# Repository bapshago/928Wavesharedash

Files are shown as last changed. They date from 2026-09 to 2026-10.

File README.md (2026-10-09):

# 928 Waveshare Dash

Dash display for the Porsche 928 EV conversion, running on the
**Waveshare ESP32-P4-WIFI6-Touch-LCD-3.4C** (3.4" round 800×800 touch display).

This is a port of the [Angry Pixie web dash](https://github.com/bapshago/AngryPixieDash)
(`leaf_dash_v9`). The CAN decoding, gauges, warnings, odometer and settings are
the same, but instead of an ESP32 serving a web page to a tablet, the data is
drawn straight onto the round screen with LVGL.

The car has **two identical units**, one each side of the dash, running the same
firmware. A menuconfig setting picks which one a unit is:

| | Left screen | Right screen |
|---|---|---|
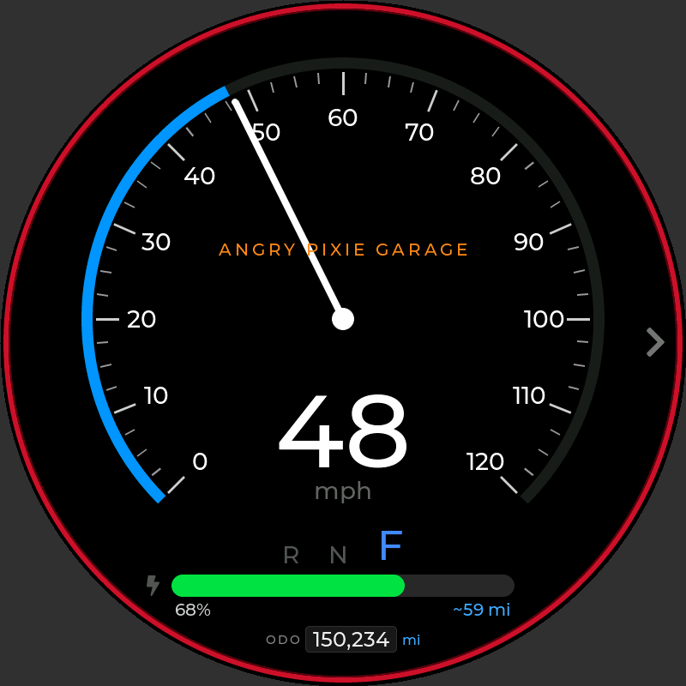
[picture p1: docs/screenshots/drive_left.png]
Left
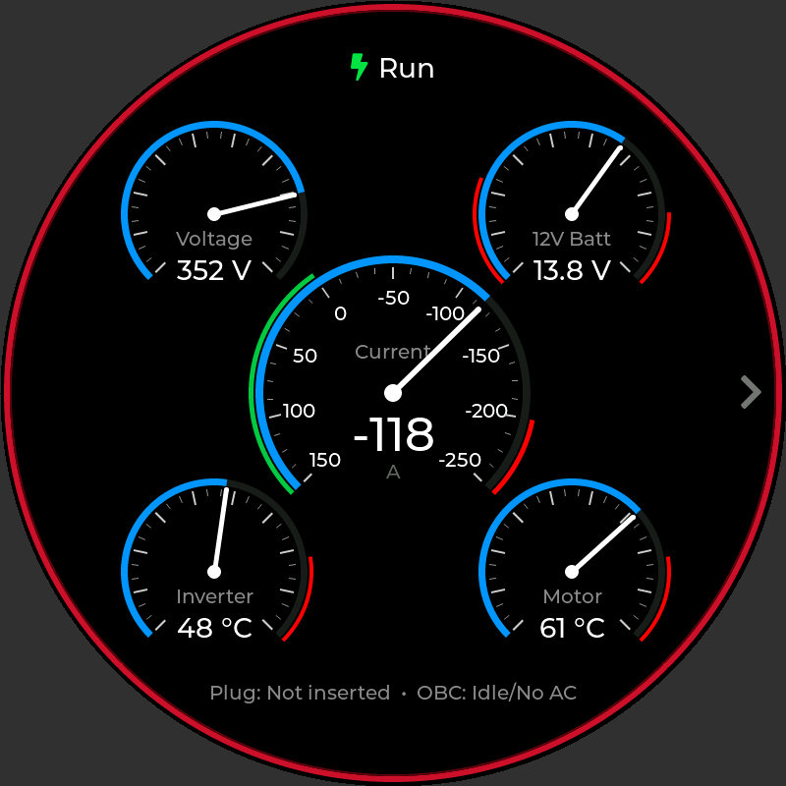
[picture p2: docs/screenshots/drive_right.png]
Right
| Driving |  |  |
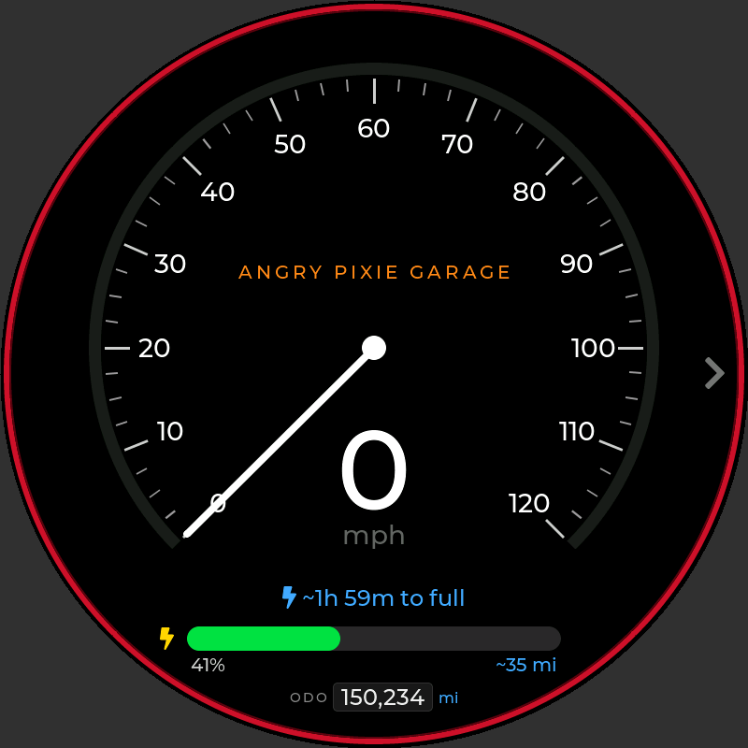
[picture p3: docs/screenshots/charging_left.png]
Charging
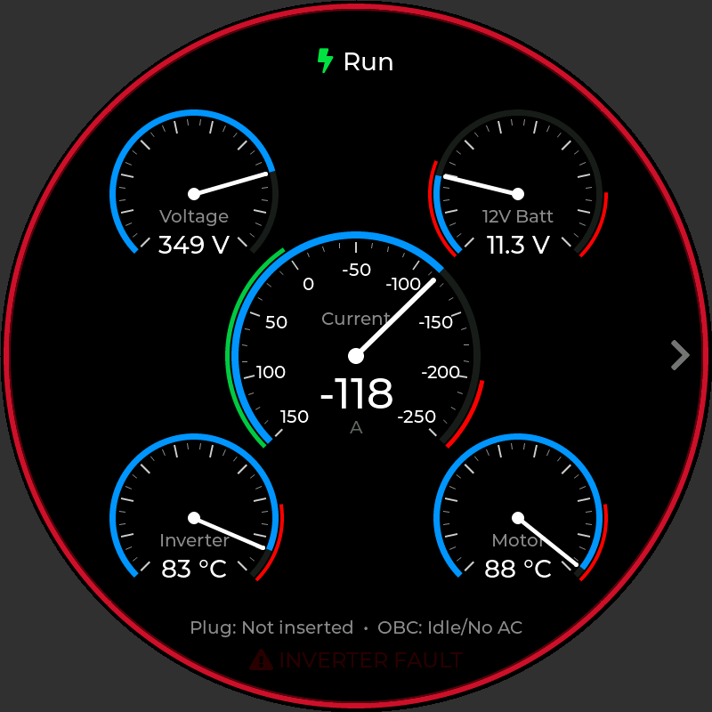
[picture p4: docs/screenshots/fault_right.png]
Fault
| Charging / fault |  |  |
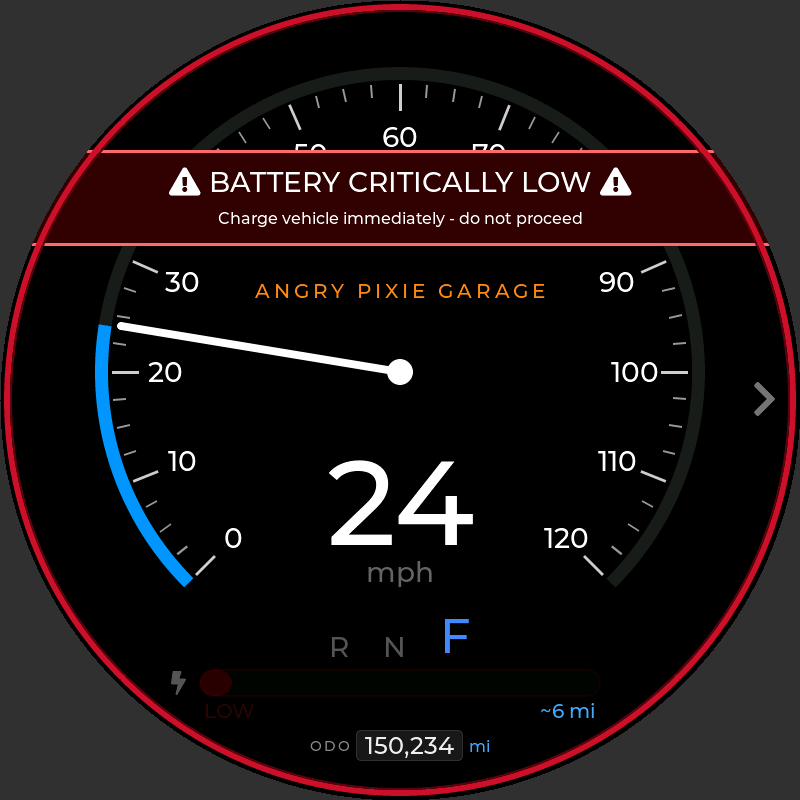
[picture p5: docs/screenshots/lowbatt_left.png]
Low battery
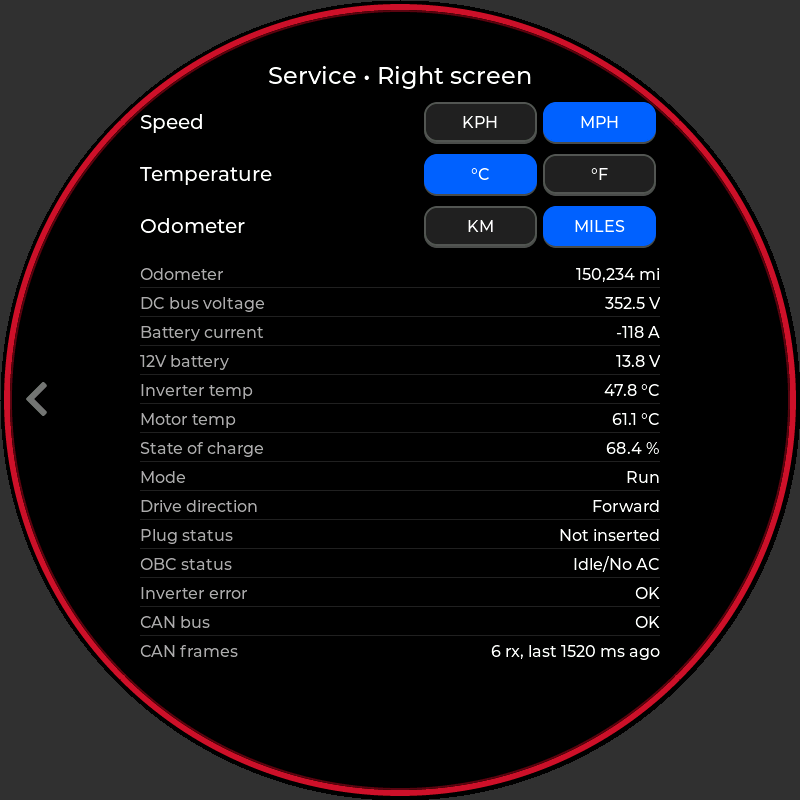
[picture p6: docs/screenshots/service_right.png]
Service
| Critically low battery / service page |  |  |

- **Left:** full-screen speed gauge, R / N / F (replaced by time-to-full while
  charging), state-of-charge bar with range, odometer, low-battery warning.
- **Right:** current gauge in the middle; pack voltage, 12V, inverter and motor
  temperature around it; op mode at the top; plug and charger status at the bottom.
- **Both:** the flashing inverter-fault warning and the service page.

*Screenshots are rendered by the desktop simulator (`sim/`) from the same UI code
the board runs; the grey corners are outside the round glass.*

## Features

Carried over from the web dash:

- Large speed gauge, kph (0–160) or mph (0–120)
- Small gauges: pack voltage, 12V aux battery (red below 11.5 V / above 15 V),
  inverter and motor temperature (°C 0–90 / °F 0–200, red in the top 20 %)
- Inverted current gauge: throttle swings clockwise to −250 A, regen to +150 A,
  green regen zone, 200–250 A redline
- R / N / F drive direction and op mode (Off, Run, Pre Charge, Pre Charge Failed, Charging)
- State-of-charge bar with range estimate (22 kWh pack, 3.9 mi/kWh); red below 15 %
- **Critical low-battery warning below 10 %**: flashing banner, bar and "LOW" readout
- Estimated time to full while charging
- Plug and on-board charger status; flashing inverter fault warning
- Odometer (miles or km), seeded to 150,000 miles on first boot and integrated from motor speed
- Service / Diagnostics screen (tap the arrow on the right edge, or swipe left) with speed, temperature and odometer unit
  toggles and all raw readings. Unit settings are stored per unit, so set them on both screens
- Unit settings and the odometer persist in flash (NVS); the odometer is written at
  most every 30 s to limit flash wear
- Red bezel ring to match the car's anodized gauge bezels

New on the round display:

- Needles ease between readings (the web page used a CSS transition)
- CAN bus state, frame counters and "last frame" age on the service screen
- 12V gauge shows one decimal (13.8 V rather than 14 V)

## Hardware

| Part | Notes |
|---|---|
| Waveshare ESP32-P4-WIFI6-Touch-LCD-3.4C | ESP32-P4, 32 MB PSRAM, 32 MB flash, 800×800 MIPI-DSI round IPS, capacitive touch |
| 3.3 V CAN transceiver: SN65HVD230 breakout | The ESP32-P4 has an on-chip CAN (TWAI) controller but no transceiver. The breakout plugs onto the board's 40-pin header |
| 12 V → 5 V buck converter (LM2596 module) | One per unit, with a USB-C lead soldered to its output to power the board. Set it to 5 V and check the polarity before plugging into the board |

Wiring (defaults; change them in `idf.py menuconfig` → *928 EV Dash*):

| 40-pin header | SN65HVD230 (breakout label) | |
|---|---|---|
| GPIO35 | D / TXD (CTX) | CAN TX |
| GPIO34 | R / RXD (CRX) | CAN RX |
| 3V3 | VCC (3V3) | |
| GND | GND | |
| | CANH / CANL | to the EV-CAN bus (ZombieVerter, Leaf inverter, PDM, BMS) |

GPIO35 is also the ESP32-P4's BOOT strapping pin. That's harmless here (the
transceiver input doesn't pull it low at power-up), but holding the board's BOOT
button will drive the CAN bus dominant, so don't press it with the car on.
The bus should already be terminated at both ends; remove the 120 Ω terminator on
the transceiver breakout unless the dash is at one end of the bus.

**Building a unit?** Follow the [build guide](docs/BUILD.md): parts, metalwork,
electronics prep, firmware, assembly, wiring into the car and commissioning.

The mechanical build is in [`hardware/mechanical/`](hardware/mechanical/README.md):
- cut files for the main instrument faceplate, the Waveshare mounting brackets,
  the buck converter bracket and the CAN bus wire bracket
- bend instructions, the hand-formed shroud, the assembly stack and hardware
- build photos

## CAN messages read (500 kbit/s)

| ID | Data |
|---|---|
| 0x1DA | DC bus voltage, motor speed, inverter error |
| 0x55A | Inverter and motor temperature |
| 0x390 | OBC / charge plug status |
| 0x55B | State of charge |
| 0x1DB | Battery current |
| 0x31A | ZombieVerter: drive direction, op mode, 12V aux voltage. Needs custom TX mappings, see [docs/ZombieVerter_CAN_Mappings.md](docs/ZombieVerter_CAN_Mappings.md) |
| 0x292 | 12V battery voltage (stock Leaf CAR-CAN, if present) |

## Building and flashing

Requires [ESP-IDF](https://docs.espressif.com/projects/esp-idf/en/latest/esp32p4/get-started/)
**v5.5 or newer** (builds verified on 5.5 and 6.1). The Waveshare BSP and LVGL are fetched automatically by the
component manager on the first build.

```sh
idf.py set-target esp32p4
idf.py build
idf.py -p /dev/ttyACM0 flash monitor     # COMx on Windows
```

Options under `idf.py menuconfig` → **928 EV Dash**:

| Option | Default | |
|---|---|---|
| Screen side | Left | **Left** or **Right**, see above. Set this differently on the two units |
| CAN TX / RX GPIO | 35 / 34 | Transceiver pins |
| CAN bitrate | 500000 | |
| Listen-only | off | On = the dash never ACKs or transmits. Leave off on a bench with only one transmitter |
| Test mode | off | No CAN needed: every gauge sweeps its full range up and back down over 20 s, SOC 100 → 0 %, and on/off states step through in turn. Test-mode distance is not added to the odometer |
| Backlight brightness | 100 % | |

The defaults target **ESP32-P4 silicon rev v1.x** (the chip on our board is
v1.3; the boot log and esptool print the revision). Newer boards ship with
v3.x silicon, and the two builds are not interchangeable: flashing reports
"requires chip revision in range ...". For a v3.x chip, build with
`idf.py -D SDKCONFIG_DEFAULTS="sdkconfig.defaults;sdkconfig.defaults.rev3_x" build`
after deleting `sdkconfig` and `build/`.

Drivetrain constants (gear ratio 7.94, tyre circumference 1.975 m, 22 kWh pack,
3.9 mi/kWh, initial odometer) are at the top of `main/core/dash_calc.h`.

## Previewing the screen without hardware

The simulator builds the same UI code for the PC and writes PNG screenshots.
It needs a C compiler and CMake:

```sh
cmake -S sim -B build-sim && cmake --build build-sim -j
./build-sim/dash_sim drive left out.png     # one scenario on one screen
./build-sim/dash_sim --all /tmp/shots        # every scenario, both screens
```

Scenarios: `drive`, `regen`, `charging`, `lowbatt`, `fault`, `nodata`,
`metric`, `service`, `test`. They're built from synthetic CAN frames run
through the real decoder, so they exercise the same path as the car.

## Tests

The CAN decoder and calculations are plain C and are tested on the PC:

```sh
cmake -S host_test -B build-test && cmake --build build-test && ./build-test/test_core
```

## Layout

```
main/
  main.c                boot: settings + CAN, then display + UI
  dash_model.c          ESP32 side: TWAI receive, NVS settings/odometer, test mode
  core/                 portable C, no ESP-IDF: state, Leaf/ZombieVerter decoder, calculations
  ui/                   LVGL: gauge widget, driver + service screens
sim/                    desktop renderer (LVGL on the PC → PNG)
host_test/              unit tests for main/core
docs/                   build guide, screenshots, ZombieVerter CAN mapping guide
hardware/mechanical/    cut files (DXF), bend diagrams, assembly notes, build photos
```

## Differences from the web dash

- **Battery current sign fix:** 0x1DB decoding now subtracts 2048 for negative
  values (the web dash subtracted 2047, so every negative reading was 1 A too high).
- **No false low-battery alarm at key-on:** SOC, pack voltage and current show
  "--" until their first CAN frame arrives. The web dash treated a missing SOC
  as 0 %, which flashed the critical-battery banner whenever data was missing.
- **Odometer display:** miles are computed as metres ÷ 1609.344 instead of
  km × 0.621371, which rounded 150,234 down to 150,233.
- **Current scale unchanged:** 0x1DB current is used at 1 A/bit, exactly as the
  web dash did. Some Leaf decodes list this signal as 0.5 A/bit, so compare the
  gauge with a clamp meter or your BMS and adjust `leaf_can.c` if it reads double.
- **Settings don't carry over:** the NVS namespace and keys match the web dash,
  but this is a different board, so the odometer seeds fresh at 150,000 miles.
  Change `DASH_ODO_INITIAL_MILES` before first boot to start from the car's real reading.

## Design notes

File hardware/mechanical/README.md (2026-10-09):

# Mechanical build

Parts, bending, the shroud and assembly for the dash pod. The DXF cut files are
in millimetres.

| File | Part | Qty (both units) | Material | How it's made |
|---|---|---|---|---|
| `SCS_MainInstrumentFaceplate_RV1_1.dxf` | Main instrument faceplate: two 90 mm gauge openings, mounting tab each end (416 × 120 mm flat) | 1 | 16 gauge (1/16") cold rolled steel | SendCutSend, then bent (below) |
| `SCS_WaveshareMountingBracket_RV1_1.dxf` | Waveshare mounting bracket: joins a Waveshare screen to the back of the faceplate (33 × 10 mm flat, two 4.5 mm holes) | 8 | 16 gauge (1/16") cold rolled steel | SendCutSend, then bent (below) |
| `SCS_BuckConverterBracket_V1_1.dxf` | Buck converter bracket, **6 round holes**: four 3 mm for the M2.5 standoffs, two 4.5 mm for M4 (attaches to the screen; flat, no bends) | 2 | 1/16" ABS | Laser cut |
| `SCS_CanBusWireBracket_V1_1.dxf` | CAN bus wire bracket, **2 round holes** (4.5 mm for M4) plus zip-tie slots; 24.8 × 88 mm (attaches to the screen; flat, no bends) | 2 | 1/16" ABS | Laser cut |
| *(no file: hand formed)* | Shroud: strip formed around the faceplate to meet the pod face | 1 | 18 gauge cold rolled steel, 3" × 31" strip | Hand formed, welded to the faceplate (below) |

## Ordering the steel parts from SendCutSend

Upload `SCS_MainInstrumentFaceplate_RV1_1.dxf` and
`SCS_WaveshareMountingBracket_RV1_1.dxf` (quantity 8), confirm the units are
**millimetres** when the part preview loads (the faceplate should show about
416 × 120 mm), and choose **cold rolled steel, 16 gauge**. SendCutSend's 16 ga steel is nominally
0.060" (1.52 mm), close enough to 1/16" (0.0625") for these parts.

## Bending the main instrument faceplate

Bend lines on the main instrument faceplate

Each end of the faceplate has a tab with a 6.5 mm hole near its top. Bend each tab
**90°** on a line **20 mm down from the top edge of the tab** (the end with the
hole). The tab is free of the main plate for its top 25 mm, so the bend line sits
5 mm above where the tab joins the faceplate; the 20 mm flap with the hole is what
folds over.

## Bending the Waveshare mounting brackets

Bend lines on the Waveshare mounting bracket

Two 90° bends in opposite directions make a **5 mm jog** (a Z shape):

1. **Bend 1:** 2 mm in from the edge of one hole, toward the middle of the part
   (about 9.3 mm from that end).
2. **Bend 2:** 5 mm past bend 1 (about 14.3 mm from the same end), back the other
   way, so the two hole ends finish parallel and 5 mm apart.

The holes sit almost exactly symmetric on the strip, so either end can be the start.

## Shroud

The shroud closes the gap between the faceplate and the face of the 928 instrument pod.
It isn't a cut file: it's hand formed from a **3" × 31" strip of 18 gauge cold
rolled steel**, using the pod as the guide.

1. **Position:** the shroud runs just inside the four inner M4 bolt holes on the faceplate
   (185 mm and 230 mm from the left end), and about 10 mm inside the four outer
   holes (110 mm and 305 mm from the left end).
2. **Measure your pod:** bolt the faceplate into the pod and measure from the edge of the faceplate
   to the face of the pod at several points around it. On the first car the
   shroud was **10 mm** at its smallest and **33 mm** at its largest, with the
   trim cut at roughly **20°**. Other pods may differ, so measure yours rather
   than copying these numbers.
3. **Make a template first (recommended):** cut a 3" × 31" strip of posterboard,
   form it around the faceplate inside the pod and trim it until it meets the pod face all
   the way round. Then trace it onto the steel strip and cut. This gets an exact
   fit before any metal is cut.
4. **Form and close:** hand form the strip to shape against the pod and trim it to
   your measurements. Then weld the two ends of the strip together.
5. **Tack weld** the shroud to the faceplate, refit it in the pod and confirm the fit.
6. **Stitch weld** the shroud to the faceplate once the fit is right.
7. **Finish:** prep for paint, then epoxy primer and a **matte black** top coat.
   Matte black keeps reflections off the screens.

## Assembly stack

Each unit stacks from the front of the car backwards:

1. **Main instrument faceplate.** One faceplate carries both screens, one per
   gauge opening.
2. **Waveshare screen**, face forward through the opening.
3. **ABS brackets** (buck converter bracket and CAN bus wire bracket) against
   the back of the screen.
4. **Four Waveshare mounting brackets** over the ABS brackets. One end of each bracket
   screws into the screen through the ABS brackets. The 5 mm jog brings the other
   end forward onto the faceplate, where it bolts on.

## Power

The buck converter's 5 V output has a USB-C cable soldered on, which plugs into
the Waveshare screen. Before plugging it into the screen, set the output to
**5 V** and **check the polarity** at the USB-C end.

## Assembly hardware

| Joint | Hardware |
|---|---|
| Waveshare mounting bracket to the Waveshare screen, clamping the ABS brackets | M4 × 5 mm screws |
| Waveshare mounting bracket to the back of the faceplate | M4 bolts, flat washers, lock washers and nuts |
| Buck converter to its ABS bracket | M2.5 × 5 mm standoffs, screws and nuts |
| Wires to the brackets | Small zip ties through the notches in the brackets |

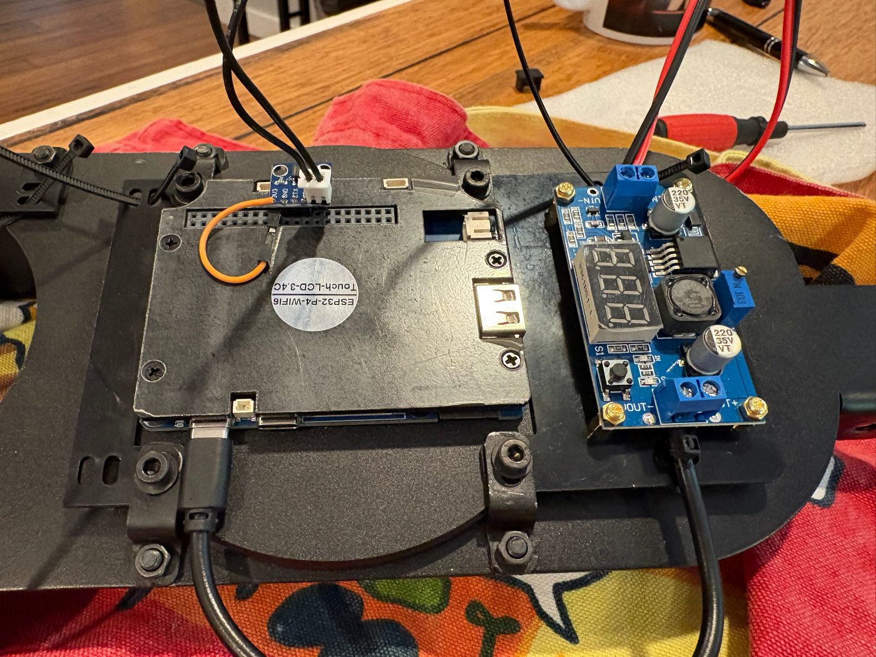
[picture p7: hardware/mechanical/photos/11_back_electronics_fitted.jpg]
Back of the main instrument faceplate with one unit assembled


*Back of the faceplate with one unit fitted:*
- *The Waveshare screen sits over a gauge opening, held by four Waveshare mounting brackets (two M4 fasteners each).*
- *The SN65HVD230 CAN transceiver plugs onto the screen's GPIO header.*
- *The LM2596 buck converter sits on M2.5 standoffs to the right.*
- *Zip ties through the bracket notches hold the wiring.*

Step-by-step assembly, wiring and commissioning are in the
[build guide](../../docs/BUILD.md).

## Build photos

In build order. All photos are in `photos/`.

**Test fit of the flat faceplate in the original 928 instrument pod**, with
one screen on its four Waveshare mounting brackets. The second opening shows the
bracket holes before its brackets go on.

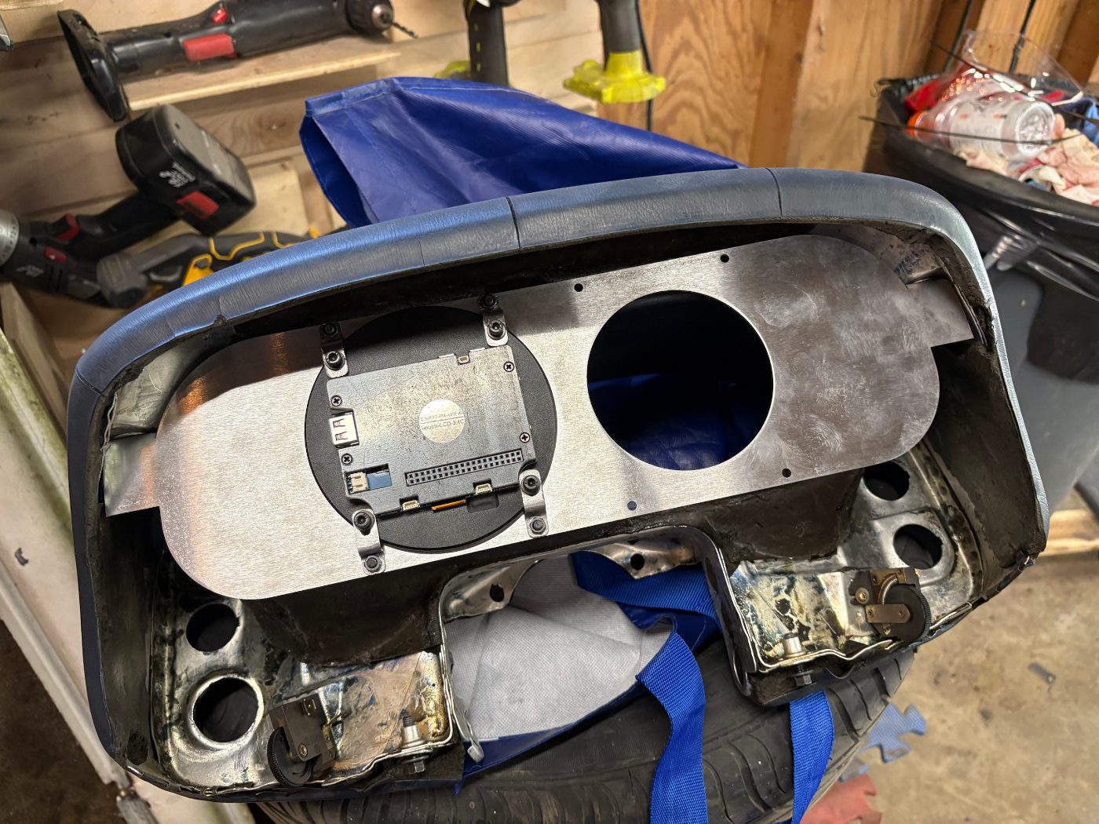
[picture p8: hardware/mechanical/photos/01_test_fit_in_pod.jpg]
Test fit in the pod

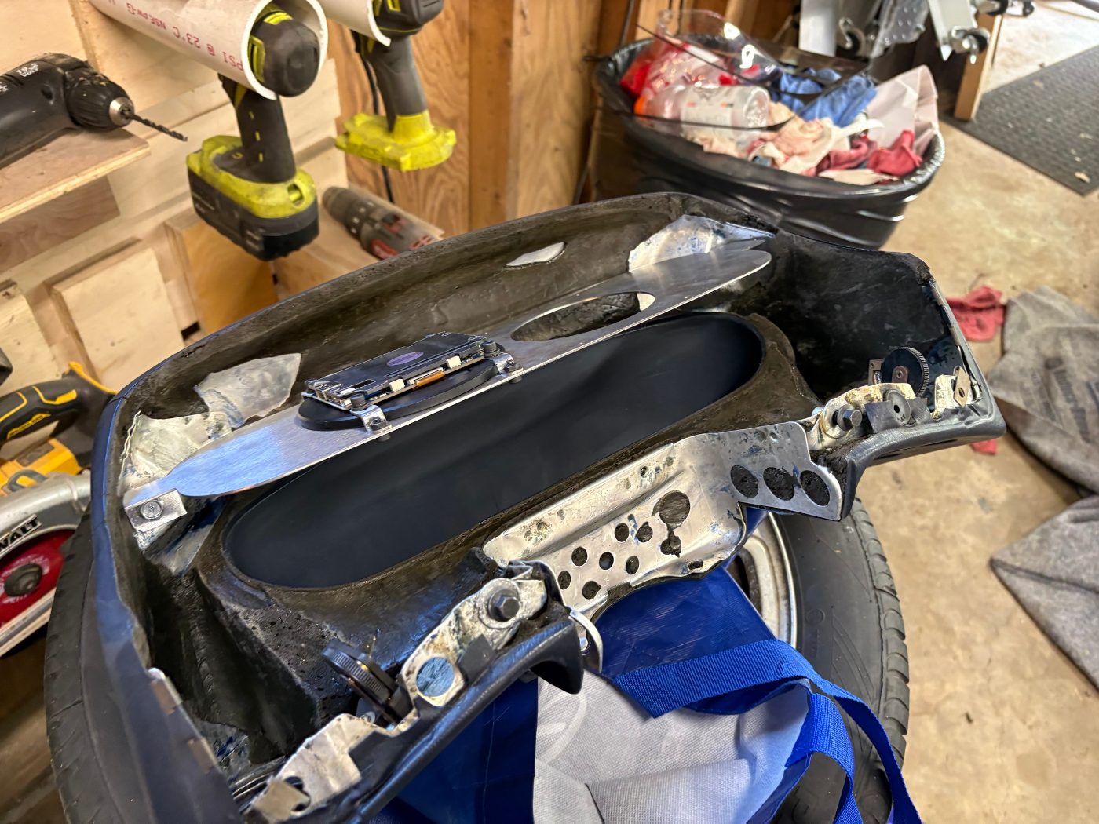
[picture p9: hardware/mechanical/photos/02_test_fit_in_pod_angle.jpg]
Test fit in the pod, side angle


**Back of the faceplate** with the Waveshare mounting brackets bolted on (M4 bolts, washers, lock
washers and nuts) and the end tabs bent.

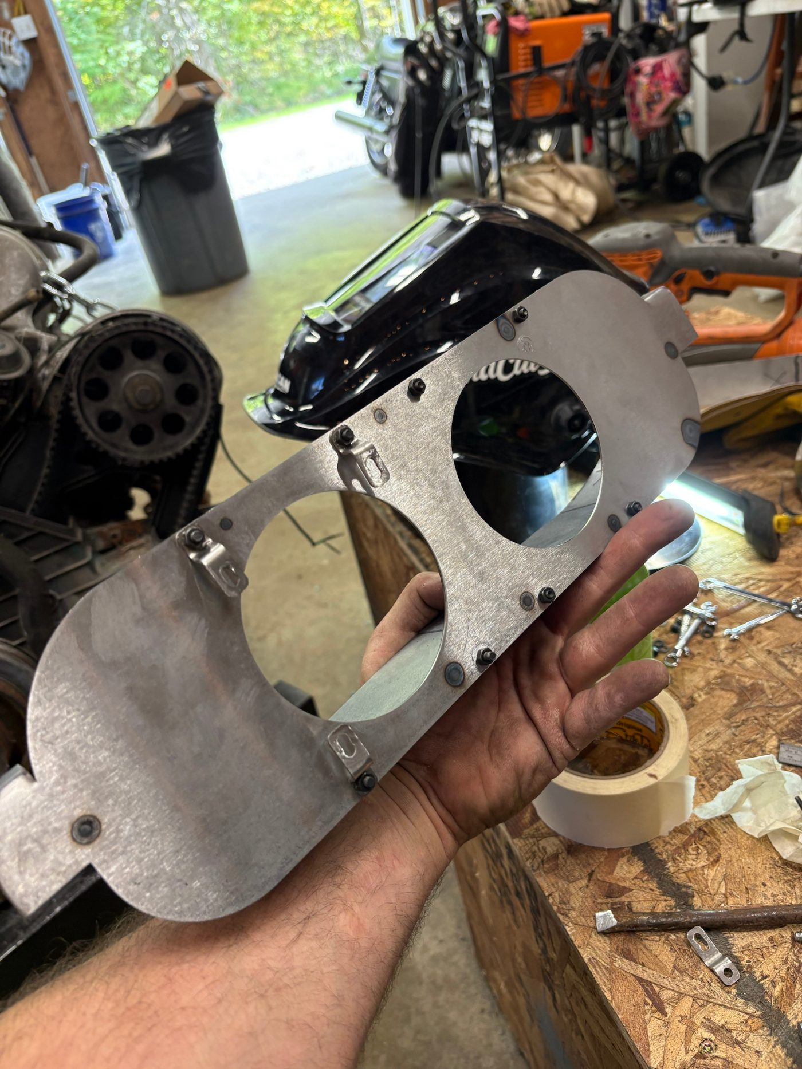
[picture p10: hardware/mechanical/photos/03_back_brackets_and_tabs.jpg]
Back of the faceplate with brackets


**Steel shroud** (see [Shroud](#shroud)), hand formed, ends welded, then tacked and
stitch welded to the faceplate.

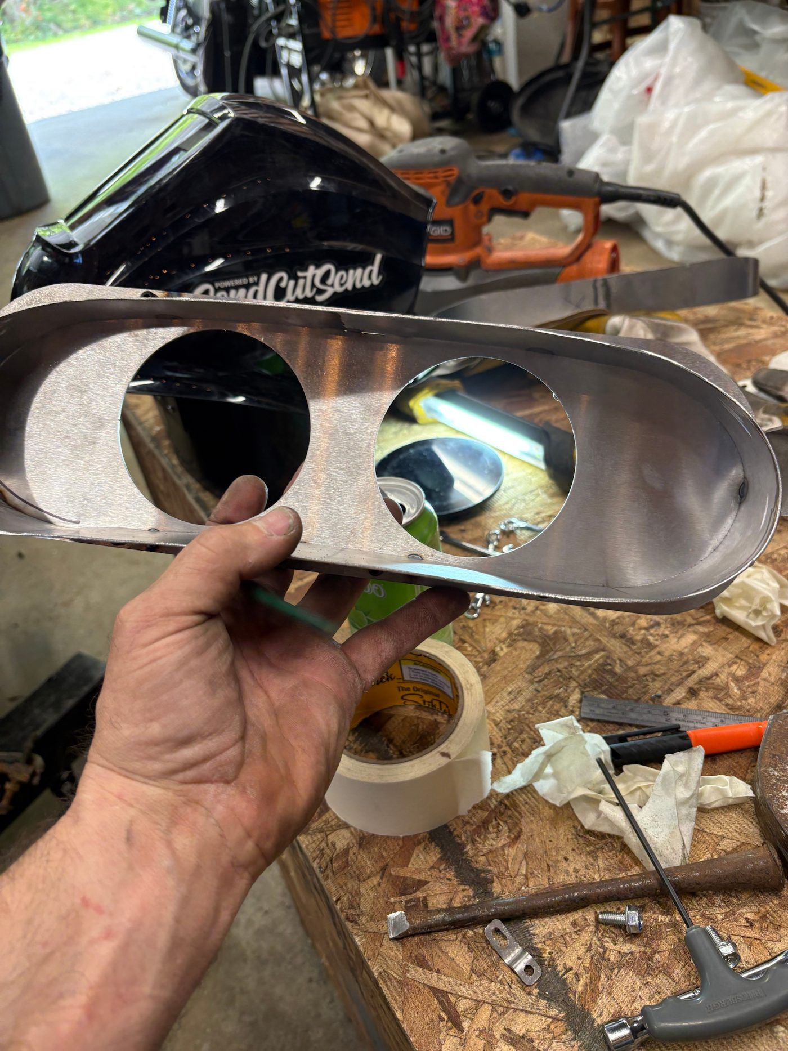
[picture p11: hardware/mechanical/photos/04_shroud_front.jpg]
Shroud from the front

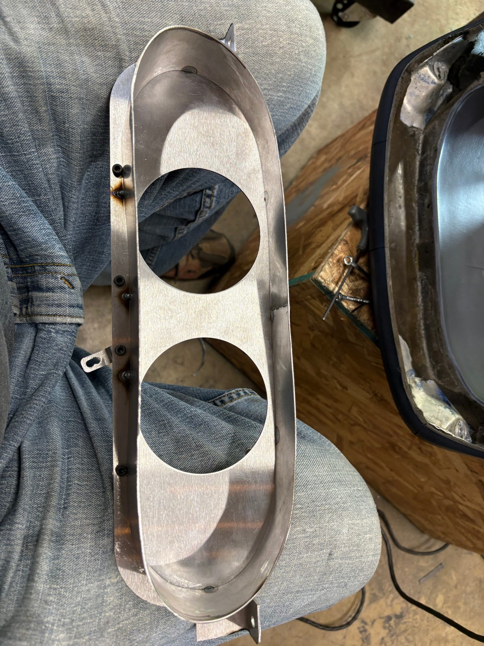
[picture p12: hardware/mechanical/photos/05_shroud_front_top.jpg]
Shroud from the front, top view

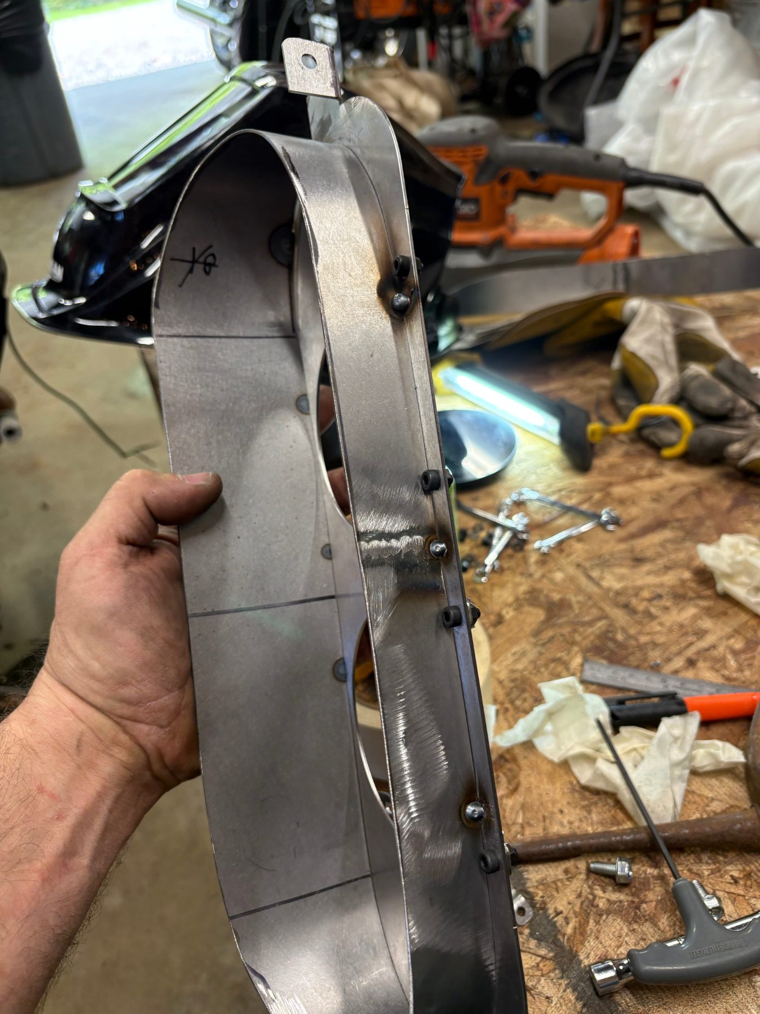
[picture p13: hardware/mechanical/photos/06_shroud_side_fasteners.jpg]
Shroud fasteners along the side

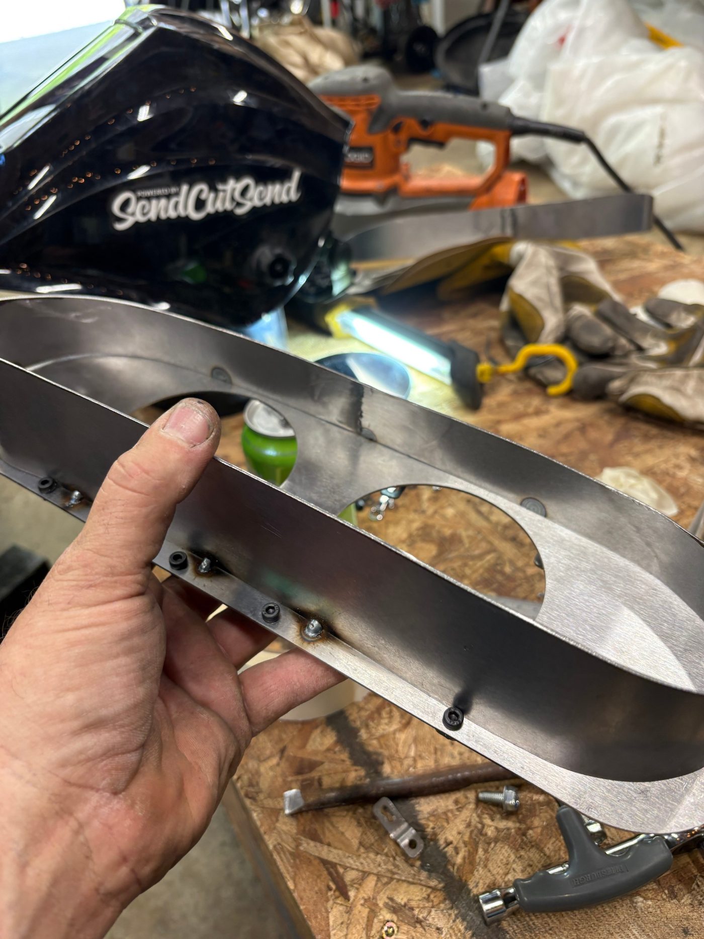
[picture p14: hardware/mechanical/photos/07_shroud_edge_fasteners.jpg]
Shroud fasteners along the edge

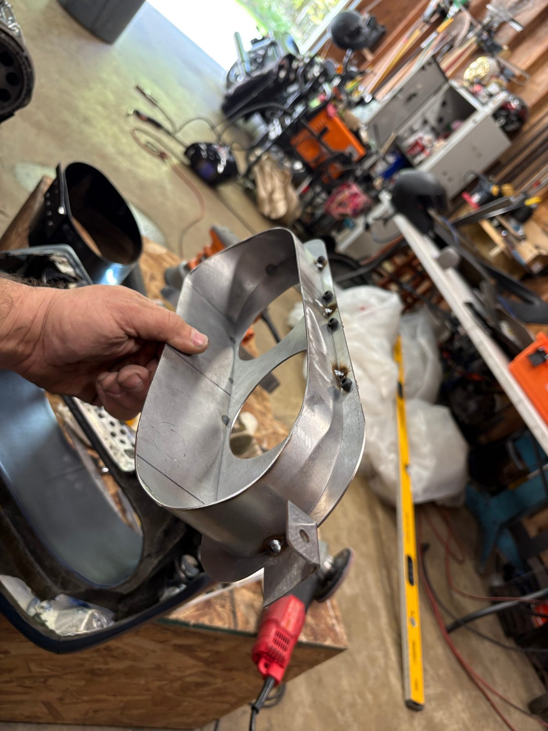
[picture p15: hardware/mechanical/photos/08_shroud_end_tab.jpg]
End tab with the shroud


**Paint:** the faceplate and the eight Waveshare mounting brackets, then the pod in grey epoxy primer. The final top coat is matte black.

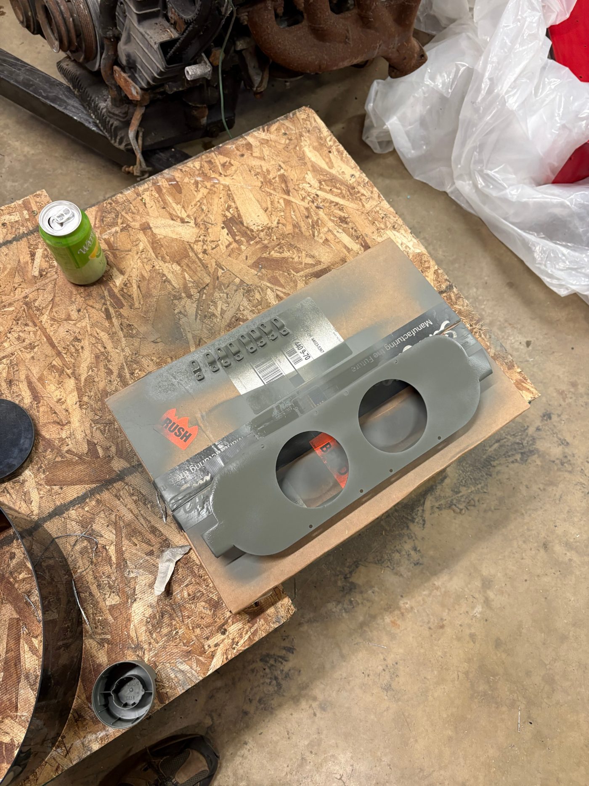
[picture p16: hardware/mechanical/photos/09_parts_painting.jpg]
Parts being painted

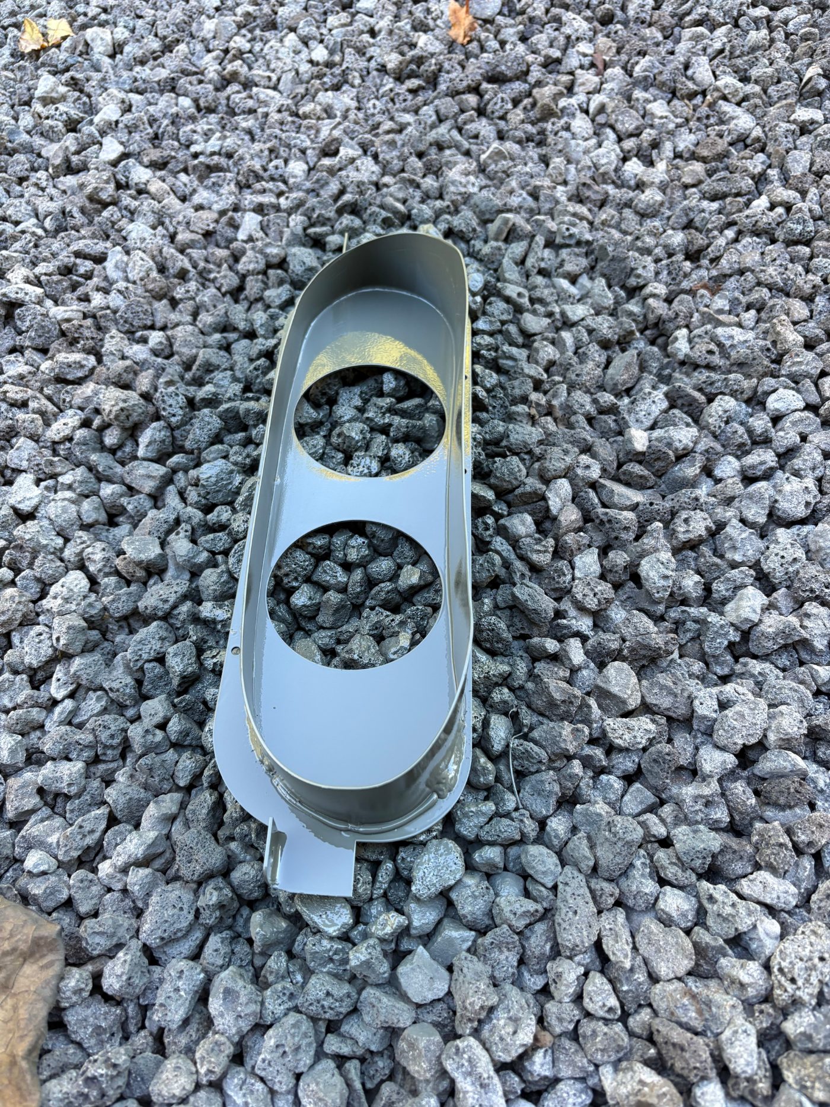
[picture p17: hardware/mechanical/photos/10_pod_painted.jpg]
Finished painted pod


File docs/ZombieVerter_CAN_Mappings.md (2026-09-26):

# ZombieVerter CAN Mappings

The dash reads three values from a custom ZombieVerter CAN TX frame on
**ID 0x31A (794 decimal)**. ZombieVerter only transmits what is explicitly
mapped, so all three mappings below must exist. If one is deleted, that
value silently stops updating on the dash (everything else keeps working).

## The three required mappings

| # | Parameter (spot value) | CAN ID | Position (start bit) | Length (bits) | Gain | Offset |
|---|---|---|---|---|---|---|
| 1 | `drivedir` | 794 (0x31A) | 0  | 8  | 1  | 0 |
| 2 | `opmode` | 794 (0x31A) | 8  | 8  | 1  | 0 |
| 3 | `uaux` | 794 (0x31A) | 16 | 16 | 10 | 0 |

As terminal/console commands (format: `can tx <param> <id> <position> <length> <gain> <offset>`):

```
can tx drivedir 794 0 8 1 0
can tx opmode   794 8 8 1 0
can tx uaux     794 16 16 10 0
```

## Resulting frame layout

| Byte(s) | Content | Decoding |
|---|---|---|
| 0 | Drive direction | 0x01 forward, 0x00 neutral, 0xFF reverse |
| 1 | Op mode | 0 off, 1 run, 2 precharge, 3 precharge fail, 4 charging |
| 2–3 | 12V battery voltage | little-endian, 0.1 V/bit (e.g. `84 00` = 0x0084 = 132 → 13.2 V) |
| 4–7 | unused | 0 |

The `uaux` gain of 10 matters: it gives 0.1 V resolution so the dash can
tell 11.4 V from 11.9 V (the gauge redline starts at 11.5 V). The ESP32
decodes bytes 2–3 by multiplying by 0.1 — if you ever change the gain, the
multiplier in `main/core/leaf_can.c` (0x31A case) must change to match.

## Adding a mapping in the ZombieVerter web UI

1. Power the ZombieVerter and connect to its WiFi network.
2. Open the ZombieVerter web interface in a browser.
3. Go to the **CAN mapping** section.
4. Add a new **TX** mapping and fill in the fields from the table above:
   parameter name, CAN ID **794**, position, length, gain (offset 0).
5. Repeat for any missing mapping — the existing entries are listed on the
   same page; compare them against the table.
6. **Save to flash** so the mappings survive a power cycle (on older
   firmware run `save` / `can save` from the console). Then power-cycle and
   confirm all three mappings are still listed.

## Verifying with the dashboard

Open the **Service** page on either screen (tap the arrow on the right edge)
and check the **Mode**, **Drive direction** and **12V battery** rows:

- Mode and drive direction change with the car but 12V shows `--` → the
  `uaux` mapping is missing.
- Mode stuck at `Off` and drive direction at `Neutral` → none of the mappings
  exist, or CAN is down (check the **CAN bus** and **CAN frames** rows).
- A plausible but wrong 12V reading → gain or byte order mismatch.

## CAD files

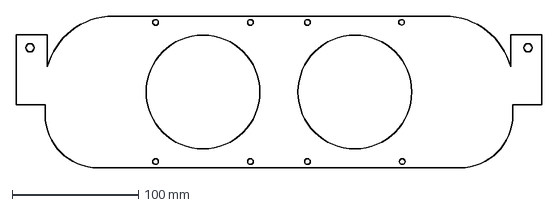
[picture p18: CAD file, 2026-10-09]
hardware/mechanical/SCS_MainInstrumentFaceplate_RV1_1.dxf
416.0 x 120.0 mm

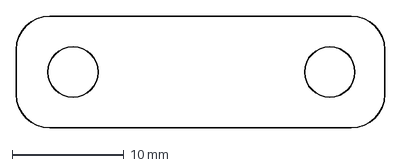
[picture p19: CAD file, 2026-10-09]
hardware/mechanical/SCS_WaveshareMountingBracket_RV1_1.dxf
33.0 x 10.00 mm

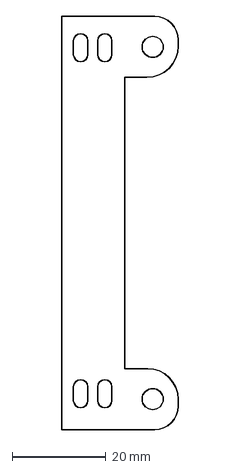
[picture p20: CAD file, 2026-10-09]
hardware/mechanical/SCS_CanBusWireBracket_V1_1.dxf
24.8 x 88.0 mm

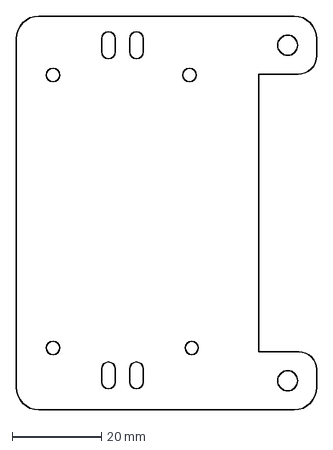
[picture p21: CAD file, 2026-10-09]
hardware/mechanical/SCS_BuckConverterBracket_V1_1.dxf
67.2 x 88.0 mm

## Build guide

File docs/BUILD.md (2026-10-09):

# Build guide: 928 EV round-screen dash

How to build the pair of round dash screens for the Porsche 928 EV, from ordering
parts to a working dash in the car. It covers both units: a **left** screen
(speed, drive direction, odometer, state of charge) and a **right** screen
(current, voltages, temperatures, status). Both run the same firmware.

Detailed reference lives elsewhere and is linked rather than repeated:

- [`hardware/mechanical/README.md`](../hardware/mechanical/README.md): cut files,
  bend diagrams, shroud, assembly stack, build photos
- [`README.md`](../README.md): wiring table, CAN messages, firmware options
- [`docs/ZombieVerter_CAN_Mappings.md`](ZombieVerter_CAN_Mappings.md): the
  ZombieVerter CAN mappings the dash needs

> **Open items** are marked like this. They're details still to be confirmed or
> photographed.

---

## 1. Parts list

Quantities are for the pair (two screens).

### Electronics

| Part | Qty | Notes |
|---|---|---|
| Waveshare ESP32-P4-WIFI6-Touch-LCD-3.4C | 2 | 3.4" round 800×800 touch display. Check the chip revision (see [Firmware](#5-firmware)) |
| SN65HVD230 CAN transceiver breakout | 2 | Pins: 3V3, GND, CTX, CRX, CANH, CANL. Plugs onto the Waveshare 40-pin header |
| LM2596 12 V → 5 V buck converter module (with voltage display) | 2 | One per screen. Rated 2.1 A each |
| USB-C cable | 2 | Cut and soldered to the buck converter output |
| Inline fuse holder and **4 A** fuse | 1 | On the 12 V feed, before the buck converters |
| Wire for 12 V power and ground | about 5 ft | Run from the CE panel. Length depends on your car |
| Wire for CAN-H / CAN-L | about 6 ft | Twisted pair recommended. Length depends on your car |

### Cut and formed parts

See the parts table in the
[mechanical README](../hardware/mechanical/README.md) for files and drawings.

| Part | Qty | Material |
|---|---|---|
| Main instrument faceplate | 1 | 16 ga (1/16") cold rolled steel, SendCutSend |
| Waveshare mounting brackets | 8 | 16 ga (1/16") cold rolled steel, SendCutSend |
| Buck converter bracket (6 round holes) | 2 | 1/16" ABS, laser cut |
| CAN bus wire bracket (2 round holes) | 2 | 1/16" ABS, laser cut |
| Shroud | 1 | 18 ga cold rolled steel strip, 3" × 31", hand formed |

### Hardware

| Item | Used for |
|---|---|
| M4 × 5 mm screws | Waveshare mounting brackets into the screens (through the ABS brackets) |
| M4 bolts, flat washers, lock washers, nuts | Waveshare mounting brackets to the faceplate |
| M2.5 × 5 mm standoffs, screws and nuts | Buck converters to their ABS brackets |
| M6 × 12 mm flange bolts (2) | Faceplate tabs to the pod, if not using the original Porsche brackets |
| Small zip ties | Wiring, through the notches in the brackets |

### Consumables

- Posterboard, for the shroud template
- Epoxy primer and matte black paint
- Solder, heat shrink

### Tools

- Sheet metal brake or vise, for the 90° bends
- Welder, for tacking and stitch welding the shroud
- Laser cutter for the ABS brackets, or a service that cuts ABS
- Soldering iron
- Multimeter
- A computer with ESP-IDF and a USB-C data cable, for flashing

---

## 2. Ordering and cutting

1. **Steel parts:** order the faceplate (qty 1) and the Waveshare mounting
   brackets (qty 8) from SendCutSend in 16 ga cold rolled steel. See
   [ordering](../hardware/mechanical/README.md#ordering-the-steel-parts-from-sendcutsend)
   for the upload checks.
2. **ABS parts:** laser cut 2 buck converter brackets and 2 CAN bus wire brackets
   from 1/16" ABS.
3. **Shroud strip:** cut a 3" × 31" strip of 18 ga cold rolled steel. Don't trim it
   yet; that happens after the template (step 3.3).

---

## 3. Metalwork

1. **Bend the faceplate tabs:** 90°, 20 mm down from the top of each end tab.
   See the [bend diagram](../hardware/mechanical/README.md#bending-the-main-instrument-faceplate).
2. **Bend the 8 Waveshare mounting brackets:** two 90° bends making a 5 mm jog.
   See the [bend diagram](../hardware/mechanical/README.md#bending-the-waveshare-mounting-brackets).
3. **Make the shroud:** test fit the faceplate in the pod, measure, make a
   posterboard template, then form, close, tack, refit and stitch weld. Follow the
   [shroud steps](../hardware/mechanical/README.md#shroud) in order. Measure your
   own pod: the first car's 10–33 mm won't necessarily fit yours.
4. **Paint:** prep, epoxy primer, then a matte black top coat on the faceplate,
   shroud and brackets. Matte black keeps reflections off the screens.

---

## 4. Electronics prep

Do this for each of the two units.

### CAN transceiver

1. Solder header pins to the SN65HVD230 breakout so it plugs onto the Waveshare
   40-pin header. CTX must go to GPIO35 and CRX to GPIO34 (see the
   [wiring table](../README.md#hardware)). If your header lands on other pins,
   change them in menuconfig to match ([Firmware](#5-firmware)).
2. **Termination:** the breakout has a 120 Ω terminating resistor (R2). The EV CAN
   bus is already terminated at both ends, so **remove R2** unless this dash is
   physically at one end of the bus.
3. Solder the CAN-H and CAN-L leads to the breakout's CANH and CANL pads.

> **Open item:** photo of the transceiver with header pins fitted and plugged in.

### Buck converter

1. Solder the USB-C cable to the buck converter's **output** terminals (OUT+ / OUT−).
2. Connect a 12 V bench supply to the **input**, then adjust the trim pot until
   the output reads **5.0 V**. Confirm with a multimeter, not just the module's
   display.
3. **Check the polarity at the USB-C end** with the multimeter (VBUS +5 V, GND)
   **before** plugging it into the Waveshare board.

> **Open item:** photo of the USB-C lead soldered to the buck converter.

---

## 5. Firmware

Full details are in the main README under
[Building and flashing](../README.md#building-and-flashing). The short version:

1. Install ESP-IDF **5.5 or newer**.
2. Check the chip revision on each board. The repo defaults are for **ESP32-P4
   rev v1.x**. For a rev v3.x chip, use the `sdkconfig.defaults.rev3_x` build in
   the README.
3. Run `idf.py menuconfig` → **928 EV Dash** and set:
   - **Screen side:** *Left* on one unit, *Right* on the other.
   - **Test mode:** *off* for the car. *On* is useful for a bench check without CAN.
   - **CAN TX / RX GPIO:** 35 / 34, unless your transceiver is on other pins.
4. Build and flash each unit:
   `idf.py build` then `idf.py -p <port> flash monitor`.
5. **Odometer:** before the first boot in the car, set `DASH_ODO_INITIAL_MILES`
   in `main/core/dash_calc.h` to the car's real mileage. It seeds once, on the
   first boot.

Because the side is a build setting, flash the left and right units one at a
time and label them.

---

## 6. Assembly

Each screen stacks, front to back:

1. **Main instrument faceplate**
2. **Waveshare screen**, face forward through its opening
3. **ABS brackets:** buck converter bracket and CAN bus wire bracket, against the
   back of the screen
4. **Four Waveshare mounting brackets**

Steps for each screen:

1. Mount the buck converter on its ABS bracket with the M2.5 × 5 mm standoffs,
   screws and nuts.
2. Lay the buck converter bracket and CAN bus wire bracket on the back of the
   screen.
3. Fit the four Waveshare mounting brackets over them and screw them into the
   screen with M4 × 5 mm screws. The screws clamp the ABS brackets in place.
4. Put the screen through its faceplate opening and bolt the other end of each
   bracket to the faceplate: M4 bolt, flat washer, lock washer and nut.
5. Plug the transceiver onto the 40-pin header and the USB-C lead into the screen.
6. Route the wires and secure them with small zip ties through the bracket notches.

The [back assembly photo](../hardware/mechanical/README.md#assembly-hardware) shows
one finished unit.

### Fitting the faceplate in the pod

Mount the faceplate in the 928 instrument pod with either:

- the **original Porsche bolt brackets**, or
- **two M6 × 12 mm flange bolts** through the 6.5 mm holes in the bent end tabs.

---

## 7. Wiring into the car

```
Terminal 15 (CE panel) ── 4 A fuse ──┬── Buck converter (left)  IN+ ── USB-C ── Left screen
                                     └── Buck converter (right) IN+ ── USB-C ── Right screen

Ground (CE panel) ───────────────────┬── Buck converter (left)  IN−
                                     └── Buck converter (right) IN−

EV CAN bus (CAN-H / CAN-L) ──┬── Left screen transceiver
                             └── Right screen transceiver
```

### 12 V power

- Take 12 V from **terminal 15 on the Porsche CE (central electrical) panel**.
  That's the switched ignition feed, so the dash is on only with the ignition.
- Fuse it with a **4 A fuse** before the buck converters.
- **One** 4 A fuse covers both buck converters: a single fused feed splits to the
  two converter inputs after the fuse.
- The first car's power run is about 5 ft to the CE panel. Size yours to your car.

> **Open item:** the ground is taken at the CE panel; the exact ground point
> is to be confirmed.

### CAN bus

- Connect both screens to the **main EV CAN bus**, the same bus as the
  ZombieVerter, BMS and inverter. The dash doesn't get everything from the
  ZombieVerter:

  | Source | What the dash reads |
  |---|---|
  | ZombieVerter (0x31A, custom mapping) | Drive direction, op mode, 12 V aux voltage |
  | Inverter (0x1DA, 0x55A) | Pack voltage, motor speed (speed and odometer), inverter fault, temperatures |
  | BMS (0x55B, 0x1DB) | State of charge, battery current |
  | Charger (0x390) | Plug and charger status |

- Set up the ZombieVerter's CAN TX mapping for 0x31A
  ([guide](ZombieVerter_CAN_Mappings.md)), or drive direction, op mode and 12 V
  won't show.
- Connect CAN-H to CAN-H and CAN-L to CAN-L. The dashes are taps on the bus, not
  its ends, so their terminators stay off (step 4).
- The first car's CAN run is about 6 ft. Size yours to your car.

---

## 8. Commissioning

### On the bench

1. Build one unit with **test mode on** and power it from its buck converter.
   Every gauge should sweep its full range and back.
2. Swipe left, or tap the arrow on the right edge, to reach the service page.
   Check that touch works.
3. Rebuild with test mode off for the car.

### In the car

1. Ignition on: both screens should start. Before the first CAN frames arrive,
   gauges show `--`.
2. Open the service page on each screen. The CAN state should read **OK**, with
   frame counters going up and a recent "last frame" time.
3. Check each reading against the source: SOC and current against the BMS,
   voltage and temperatures against the inverter, and drive direction and op mode
   against the ZombieVerter.
4. Set the units (mph / km/h and °F / °C) on the service page. **Do this on both
   screens**, because settings are stored per unit.
5. Check the odometer against the car's mileage.
6. Drive: check speed against GPS and that R / N / F follows the selector.

---

## 9. Troubleshooting

| Symptom | Cause and fix |
|---|---|
| Flashing fails: *"requires chip revision in range [v3.0 - v3.99] (this chip is revision v1.3)"* | The build doesn't match the chip revision. Delete `sdkconfig` and `build/`, then rebuild with the right defaults for your chip (see [Firmware](#5-firmware)) |
| Build errors on ESP-IDF 6.x after updating the repo | An old `sdkconfig` or `managed_components/` is left over. Delete `sdkconfig`, `build/` and `managed_components/`, then rebuild |
| Screen works but no CAN frames (service page counters stay at 0) | Check the CTX/CRX pins match menuconfig (TX 35, RX 34 by default); on the first unit RX was wired to 34 when the setting said 36. Then check CAN-H / CAN-L aren't swapped, the bus is at 500 kbit/s, and listen-only is off on a bench |
| Some gauges stay `--` while others work | Their source isn't sending on this bus. Drive direction, op mode and 12 V need the ZombieVerter 0x31A mapping; SOC and current come from the BMS; temperatures from the inverter |
| Current reads about double | Some Leaf decodes use 0.5 A/bit. Compare with a clamp meter; see "Differences" in the main README |
| Screen doesn't power up | Check the fuse, terminal 15 is live with the ignition on, the buck converter output is 5 V and the USB-C polarity |
| Holding the board's BOOT button upsets the CAN bus | GPIO35 (CAN TX) is also the BOOT pin. Don't press BOOT with the car on |

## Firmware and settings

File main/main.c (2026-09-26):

// Porsche 928 EV dash on the Waveshare ESP32-P4-WIFI6-Touch-LCD-3.4C.
//
// Port of the Angry Pixie web dash (leaf_dash_v9): instead of serving a web
// page to a tablet, the same CAN data is drawn straight onto the 800x800
// round touch display with LVGL.
#include "bsp/esp-bsp.h"
#include "esp_log.h"
#include "sdkconfig.h"

#include "dash_model_esp.h"
#include "dash_ui.h"

static const char *TAG = "main";

void app_main(void)
{
    ESP_LOGI(TAG, "928 EV dash booting");
    ESP_ERROR_CHECK(dash_model_start());

    // Display + touch + LVGL task, as in Waveshare's 08_lvgl_demo_v9 example.
    bsp_display_cfg_t cfg = {
        .lv_adapter_cfg = ESP_LV_ADAPTER_DEFAULT_CONFIG(),
        .rotation = ESP_LV_ADAPTER_ROTATE_0,
        .tear_avoid_mode = ESP_LV_ADAPTER_TEAR_AVOID_MODE_TRIPLE_PARTIAL,
        .touch_flags = { .swap_xy = 0, .mirror_x = 0, .mirror_y = 0 },
    };
    if (bsp_display_start_with_config(&cfg) == NULL) {
        ESP_LOGE(TAG, "display start failed");
        return;
    }

#if CONFIG_DASH_SIDE_RIGHT
    const dash_side_t side = DASH_SIDE_RIGHT;
#else
    const dash_side_t side = DASH_SIDE_LEFT;
#endif
    ESP_LOGI(TAG, "screen side: %s", side == DASH_SIDE_LEFT ? "left" : "right");

    bsp_display_lock(-1);
    dash_ui_create(lv_screen_active(), side);
    bsp_display_unlock();

    bsp_display_brightness_set(CONFIG_DASH_BRIGHTNESS);
    ESP_LOGI(TAG, "dash running");
}

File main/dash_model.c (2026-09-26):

// ESP32-P4 implementation of dash_model.h: TWAI (CAN) receive, NVS-backed
// settings and odometer, and test mode. Replaces the CAN task, Preferences
// and /api endpoints of leaf_dash_v9.ino.
#include "dash_model.h"

#include <math.h>
#include <string.h>

#include "esp_check.h"
#include "esp_log.h"
#include "esp_timer.h"
#include "esp_twai.h"
#include "esp_twai_onchip.h"
#include "freertos/FreeRTOS.h"
#include "freertos/queue.h"
#include "freertos/semphr.h"
#include "freertos/task.h"
#include "nvs.h"
#include "nvs_flash.h"
#include "sdkconfig.h"

#include "dash_model_esp.h"
#include "leaf_can.h"

static const char *TAG = "dash_model";

#if CONFIG_DASH_CAN_LISTEN_ONLY
#define CAN_LISTEN_ONLY 1
#else
#define CAN_LISTEN_ONLY 0
#endif

// Same NVS namespace and keys as the web dash's Preferences, so the layout is familiar.
#define NVS_NAMESPACE        "apdash"
#define ODO_TICK_MS          250      // integrate ~4x/second
#define ODO_SAVE_INTERVAL_MS 30000    // flash-wear limit: worst case a power cut loses 30 s of distance

typedef struct {
    uint32_t id;
    uint8_t  dlc;
    uint8_t  data[8];
} rx_msg_t;

static SemaphoreHandle_t s_lock;
static dash_state_t      s_state;
static dash_settings_t   s_settings;
static double            s_odo_m;
static dash_can_state_t  s_can_state = DASH_CAN_DOWN;
static nvs_handle_t      s_nvs;

static inline uint32_t now_ms(void) { return (uint32_t)(esp_timer_get_time() / 1000); }

// ── snapshot API used by the UI ────────────────────────────────────────────

void dash_model_snapshot(dash_snapshot_t *out)
{
    xSemaphoreTake(s_lock, portMAX_DELAY);
    out->vehicle = s_state;
    out->settings = s_settings;
    out->odo_m = s_odo_m;
    out->can_state = s_can_state;
    xSemaphoreGive(s_lock);
    out->now_ms = now_ms();
}

void dash_model_set_settings(const dash_settings_t *cfg)
{
    xSemaphoreTake(s_lock, portMAX_DELAY);
    bool changed = memcmp(&s_settings, cfg, sizeof(*cfg)) != 0;
    s_settings = *cfg;
    xSemaphoreGive(s_lock);
    if (!changed) {
        return;
    }
    // Retained across reboots, like the web dash's /api/set* handlers.
    nvs_set_u8(s_nvs, "use_mph", cfg->use_mph);
    nvs_set_u8(s_nvs, "use_f", cfg->use_fahrenheit);
    nvs_set_u8(s_nvs, "odo_mi", cfg->use_odo_miles);
    nvs_commit(s_nvs);
    ESP_LOGI(TAG, "settings: mph=%d f=%d odo_mi=%d", cfg->use_mph, cfg->use_fahrenheit, cfg->use_odo_miles);
}

// ── NVS ────────────────────────────────────────────────────────────────────

static bool prefs_get_bool(const char *key, bool dflt)
{
    uint8_t v;
    return nvs_get_u8(s_nvs, key, &v) == ESP_OK ? v != 0 : dflt;
}

// Doubles are stored as their raw 64-bit pattern.
static void prefs_put_double(const char *key, double v)
{
    uint64_t raw;
    memcpy(&raw, &v, sizeof(raw));
    nvs_set_u64(s_nvs, key, raw);
}

static bool prefs_get_double(const char *key, double *out)
{
    uint64_t raw;
    if (nvs_get_u64(s_nvs, key, &raw) != ESP_OK) {
        return false;
    }
    memcpy(out, &raw, sizeof(*out));
    return isfinite(*out);
}

static esp_err_t load_persisted(void)
{
    esp_err_t err = nvs_flash_init();
    if (err == ESP_ERR_NVS_NO_FREE_PAGES || err == ESP_ERR_NVS_NEW_VERSION_FOUND) {
        ESP_ERROR_CHECK(nvs_flash_erase());
        err = nvs_flash_init();
    }
    ESP_RETURN_ON_ERROR(err, TAG, "nvs init");
    ESP_RETURN_ON_ERROR(nvs_open(NVS_NAMESPACE, NVS_READWRITE, &s_nvs), TAG, "nvs open");

    s_settings.use_mph = prefs_get_bool("use_mph", false);
    s_settings.use_fahrenheit = prefs_get_bool("use_f", false);
    s_settings.use_odo_miles = prefs_get_bool("odo_mi", false);
    if (!prefs_get_double("odo_m", &s_odo_m)) {
        s_odo_m = 0.0;
    }

    // One-time odometer seed: set the starting reading once on a device that has
    // never been seeded, then never overwrite it so real accumulated mileage is
    // preserved. Erasing flash re-seeds it.
    if (!prefs_get_bool("odo_seeded", false)) {
        s_odo_m = DASH_ODO_INITIAL_MILES * DASH_METERS_PER_MILE;
        prefs_put_double("odo_m", s_odo_m);
        nvs_set_u8(s_nvs, "odo_seeded", 1);
        nvs_commit(s_nvs);
        ESP_LOGI(TAG, "odometer seeded to %.0f miles", DASH_ODO_INITIAL_MILES);
    }
    ESP_LOGI(TAG, "prefs: mph=%d f=%d odo_mi=%d odo=%.1f km", s_settings.use_mph, s_settings.use_fahrenheit,
             s_settings.use_odo_miles, s_odo_m / 1000.0);
    return ESP_OK;
}

#if !CONFIG_DASH_TEST_MODE  // test mode never starts CAN
static QueueHandle_t      s_rx_queue;
static twai_node_handle_t s_node;

// ── CAN ────────────────────────────────────────────────────────────────────

static bool IRAM_ATTR on_rx_done(twai_node_handle_t node, const twai_rx_done_event_data_t *edata, void *ctx)
{
    rx_msg_t msg = { 0 };
    twai_frame_t frame = { .buffer = msg.data, .buffer_len = sizeof(msg.data) };
    if (twai_node_receive_from_isr(node, &frame) != ESP_OK) {
        return false;
    }
    if (frame.header.ide || frame.header.rtr) {
        return false;  // Leaf / ZombieVerter frames are standard 11-bit data frames
    }
    msg.id = frame.header.id;
    msg.dlc = frame.header.dlc > 8 ? 8 : (uint8_t)frame.header.dlc;
    BaseType_t woken = pdFALSE;
    xQueueSendFromISR(s_rx_queue, &msg, &woken);
    return woken == pdTRUE;
}

static bool IRAM_ATTR on_state_change(twai_node_handle_t node, const twai_state_change_event_data_t *edata,
                                      void *ctx)
{
    static const dash_can_state_t map[] = {
        [TWAI_ERROR_ACTIVE] = DASH_CAN_OK,
        [TWAI_ERROR_WARNING] = DASH_CAN_WARNING,
        [TWAI_ERROR_PASSIVE] = DASH_CAN_PASSIVE,
        [TWAI_ERROR_BUS_OFF] = DASH_CAN_BUS_OFF,
    };
    s_can_state = map[edata->new_sta];  // single aligned word write; read under the lock elsewhere
    return false;
}

static void can_rx_task(void *arg)
{
    rx_msg_t msg;
    for (;;) {
        if (xQueueReceive(s_rx_queue, &msg, pdMS_TO_TICKS(1000)) != pdTRUE) {
            if (s_can_state == DASH_CAN_BUS_OFF) {
                ESP_LOGW(TAG, "bus off, recovering");
                twai_node_recover(s_node);
            }
            continue;
        }
        uint32_t t = now_ms();
        xSemaphoreTake(s_lock, portMAX_DELAY);
        s_state.frames_rx++;
        s_state.last_rx_ms = t ? t : 1;
        if (leaf_can_decode(msg.id, msg.data, msg.dlc, &s_state)) {
            s_state.frames_decoded++;
        }
        xSemaphoreGive(s_lock);
    }
}
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

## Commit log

2026-09-25 Port Angry Pixie web dash to the Waveshare ESP32-P4 3.4" round display
    ESP-IDF + LVGL 9 firmware for the ESP32-P4-WIFI6-Touch-LCD-3.4C. Same
    Leaf/ZombieVerter CAN decoding, gauges, warnings, odometer and unit
    settings as leaf_dash_v9, drawn on the 800x800 round screen instead of
    served to a tablet over WiFi.
    - main/core: portable CAN decoder and calculations (host-tested)
    - main/ui: gauge widget, driver screen and swipe-in service screen
    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
    [partitions.csv]
2026-09-25 Pin LVGL to 9.5 so the build works on ESP-IDF 6.x
    LVGL 9.6 moved its public headers and emits #warning for the old src/
    paths. esp_lvgl_adapter still includes those paths, and ESP-IDF 6.x
    treats default warnings as errors, so the build failed in
    lvgl_ppa_accel_v9.c. Pin lvgl ~9.5.0 (firmware and simulator) and set
    COMPILER_DISABLE_DEFAULT_ERRORS=y so third-party warnings can't stop
    the build.
    Claude-Session: https://claude.ai/code/session_01NcqWUjMkxaoxiSK65VTNg6
2026-09-26 Rename NVS helpers so the build works on ESP-IDF 6.1
    ESP-IDF 6.1 added nvs_get_double(), which collided with the static helper
    of the same name in dash_model.c ("conflicting types for
    'nvs_get_double'"). Rename the local helpers to prefs_*. The stored
    format is unchanged (u64 bit pattern), so saved odometer values still load.
    Verified: firmware builds on ESP-IDF 5.5.5 and 6.1.
    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
    [dash_model.c]
2026-09-26 Build for ESP32-P4 silicon rev v1.x by default
    The board on hand has a v1.3 ESP32-P4, and flashing the rev v3.x build
    failed with "requires chip revision in range [v3.0 - v3.99]". Default to
    pre-v3 silicon (REV_MIN 1.0, PSRAM 200 MHz, as in Waveshare's rev1_3
    profile); README explains how to build for v3.x boards instead.
    Verified: builds on ESP-IDF 5.5.5 and 6.1; images report chip revision
    range v1.0-v1.99.
    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
2026-09-26 Make the page arrows tappable
    The chevron at the right edge of the driver screen was only a swipe hint,
    so tapping it did nothing. Turn both chevrons into large tap targets
    (driver → service, service → driver) that brighten while pressed, and
    make them more visible. Swiping still works.
    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
2026-09-26 Linear test-mode sweeps, snappier touch, no test miles on the odometer
    Test mode: every gauge now sweeps its full range linearly (bottom to top
    over 10 s and back) in one shared 20 s cycle, SOC runs 100 -> 0 % so the
    low-battery warning shows, and R/N/F, op mode, plug and OBC states step
    through in order. The inverter fault shows for one 3 s step per cycle
    instead of flashing constantly. Test-mode distance no longer counts
    toward the odometer.
    Touch responsiveness: the UI restyled every label and redrew every needle
    20 times a second even when nothing changed, and kept updating the hidden
    page. Only touch what changed, refresh only the visible page, and replace
    the large blurred bezel glow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
    [dash_calc.c, dash_model.c, dash_ui.c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]
2026-09-26 Split the dash across left and right screens
    The car gets two identical units running the same firmware; a new
    menuconfig option (928 EV Dash -> Screen side) picks which one a unit is,
    and only that side's driver page is built.
    - Left: full-screen speed gauge (r 305, 120 px digits-only speed font),
    R/N/F (time-to-full while charging), SOC bar + range, odometer,
    low-battery banner.
    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
2026-10-07 Move the CAN transceiver to GPIO35 (TX) / GPIO36 (RX)
    The breakout is now wired to GPIO35 (CTX) and GPIO36 (CRX) on the 40-pin
    header. Make those the menuconfig defaults and update the README wiring
    table. Neither pin is used by the Waveshare BSP. GPIO35 doubles as the
    ESP32-P4 BOOT strapping pin, which is noted in the help text and README.
    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
2026-10-07 CAN RX on GPIO34 to match the wiring
    The transceiver's CRX is wired to GPIO34, not GPIO36. Make 34 the RX
    default (TX stays on GPIO35) and update the README. GPIO34 isn't used
    by the Waveshare BSP.
    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
2026-10-09 Add laser-cut DXFs for dash brackets
    Instrument cluster bracket and the two buck converter mounting plates,
    under hardware/mechanical/ with a short README.
    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
    [InstrumentClusterBracket1_v1_1.dxf, SCS_BuckConverterForDash_Plate2_V1_1.dxf, SCS_BuckConverterForDash_Plate_V1_1.dxf]
2026-10-09 Document bracket materials; add CAN cable holder
    Instrument cluster bracket: 16 ga (1/16") cold rolled steel from SendCutSend.
    Buck converter plates and CAN cable holder: 1/16" ABS.
    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
2026-10-09 Document instrument cluster bracket bend
    90 degree bend 20 mm in from the hole end of the tabs, with a diagram.
    Also correct the flat part size in the SendCutSend note (about 67 x 88 mm).
    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
2026-10-09 Remove bend diagram drawn on the wrong part
    The InstrumentClusterBracket DXF has the buck converter plate's outline, so the
    diagram showed the wrong part. Keep the bend instruction as text until the
    correct drawing is added.
    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
2026-10-09 Add instrument cluster plate and strip DXFs with bend diagram
    cut3 is the instrument cluster plate (two 90 mm gauge openings); its end tabs
    bend 90 degrees 20 mm down from the top of the tab. cut4 is a small strip that
    also bends; its bend is still to be documented.
    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
    [InstrumentCluster_RV1_1_cut3_SCS.dxf, InstrumentCluster_RV1_1_cut4_SCS.dxf]
2026-10-09 Document screen bracket bends and assembly hardware
    cut4: two 90 degree bends making a 5 mm jog, 2 mm from the hole edge and 5 mm
    apart, with a diagram. Note the M4 x 5 mm and M2.5 x 5 mm hardware, the ABS
    brackets being flat, and the zip-tie notches.
    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
2026-10-09 Add photo of the assembled back of the instrument cluster
    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
2026-10-09 Document part quantities, assembly stack and buck converter setup
    Remove InstrumentClusterBracket1 (not a real part). 8 cut4 brackets; stack is
    cut3, screen, ABS brackets, cut4 brackets bolted to cut3 with M4 bolts, washers,
    lock washers and nuts. Buck converter set to 5 V and polarity checked before
    the soldered USB-C lead goes to the screen.
    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
    [InstrumentClusterBracket1_v1_1.dxf]
2026-10-09 Add build photos of the instrument pod
    Test fit in the original pod, brackets and bent tabs, the steel shroud, and
    paint. Photos resized to 1400 px with metadata stripped.
    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
2026-10-09 Document the hand-formed shroud and paint finish
    18 ga cold rolled 3 x 31 in strip, formed against the pod, ends welded, tacked
    then stitch welded to cut3; measure each pod (10-33 mm, ~20 deg on the first
    car). Epoxy primer and matte black top coat.
    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
2026-10-09 Recommend a posterboard template for the shroud
    Also give the inner/outer bolt hole positions on cut3.
    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
2026-10-09 Identify Plate2 as the CAN bus wire bracket; drop duplicate .xcs
    The xTool project held the same part as SCS_BuckConverterForDash_Plate2.
    Quantities: 2 buck converter brackets, 2 CAN bus wire brackets.
    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
2026-10-09 Rename Plate2 DXF to SCS_CanBusWireBracket_V1_1.dxf
    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
    [SCS_CanBusWireBracket_V1_1.dxf]
2026-10-09 Rename faceplate and Waveshare bracket files; update docs
    cut3 -> SCS_MainInstrumentFaceplate_RV1_1.dxf, cut4 ->
    SCS_WaveshareMountingBracket_RV1_1.dxf (bend diagrams renamed to match).
    Use the new part names throughout the mechanical README, and link the
    mechanical docs from the main README.
    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
    [SCS_MainInstrumentFaceplate_RV1_1.dxf, SCS_WaveshareMountingBracket_RV1_1.dxf]
2026-10-09 Rename buck converter bracket DXF; refresh stale docs
    SCS_BuckConverterForDash_Plate_V1_1.dxf -> SCS_BuckConverterBracket_V1_1.dxf.
    Main README: name the LM2596 buck converter and its 5 V USB-C lead, note the
    transceiver breakout plugs onto the header, realign the layout tree.
    CLAUDE.md: describe hardware/mechanical/. Mechanical README retitled.
    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
    [SCS_BuckConverterBracket_V1_1.dxf]
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2026-10-12 Make the ESP32-P4 chip revision a menuconfig option
    The second Waveshare board has a v3.2 chip and the v1.x build refused to
    flash on it. Add 928 EV Dash -> ESP32-P4 chip revision (v1.x / v3.x); v1.x
    selects ESP-IDF's ESP32P4_SELECTS_REV_LESS_V3, so it is no longer set in
    sdkconfig.defaults, and the rev1_3 / rev3_x defaults files go away.
    An sdkconfig from before this change can hold that IDF option as a saved
    value that a v3.x choice can't clear; main/CMakeLists.txt now stops the
    build with instructions in that case. PSRAM stays at 200 MHz for both.
    Verified on ESP-IDF 5.5 and 6.1: v1.x bootloader accepts v1.0-v1.99, v3.x
    accepts v3.1-v3.99; switching in either direction updates the IDF o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
2026-10-15 Make tyre size and gear ratio configurable in menuconfig
    Speed and the odometer are calculated from motor RPM, the gear ratio and the
    driven tyres' circumference, so a wrong fixed value misreports mileage. New
    submenu 928 EV Dash -> Speed and odometer calibration: tyre size as a
    measured rolling circumference (default 1975 mm) or a sidewall size such as
    245/45R16, plus the overall gear ratio x1000 (default 7940). Defaults keep
    the previous values. The boot log prints the calibration in use.
    core/ stays portable: dash_calc.h reads sdkconfig.h only when main/
    defines DASH_HAVE_SDKCONFIG; host tests and the sim use the same defaults.
    Host tests cover the sidewall-size formula. Firmware built o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
